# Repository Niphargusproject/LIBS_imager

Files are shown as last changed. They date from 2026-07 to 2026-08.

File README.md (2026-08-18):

# LIBS elemental imager

Design files, firmware and software of a laboratory laser-induced breakdown
spectroscopy (LIBS) elemental imager built from low-cost CNC-derived components,
with a fully hardware-triggered acquisition chain.

The instrument moves the sample under a fixed laser and fixed collection optics on
three ball-screw linear stages driven by the open-source Grbl_ESP32 firmware. The
stepper step pulses of the scan axis are counted and divided by an Arduino-based
pulse controller, which triggers the laser, and the laser in turn triggers the
spectrometers. Shot spacing is therefore locked to stage position instead of to
software timing. A Python/PyQt5 application streams dark-corrected,
wavelength-concatenated spectra into a compressed NetCDF4 hyperspectral cube; a
second application reads those cubes and produces elemental maps, ratios and RGB
composites.

Although it is demonstrated here for LIBS, the motion, triggering and data-cube
chain is technique-agnostic: it can drive other point-by-point mapping methods such
as UV fluorescence, FTIR or Raman imaging.

This repository is the reference implementation for the article:

> C. Burlet, S. Bengattat, X. Devleeschouwer, H. Goethals, T. Goovaerts, M. Rossi,
> G. Stasi, A. Tovar, Y. Vanbrabant, S. Verheyden, R. Barros, S. Nachtergaele,
> E. Pirard. *A Laser-Induced Breakdown Spectroscopy (LIBS) elemental imager built
> from CNC-derived components with a fully hardware-triggered acquisition chain.*
> HardwareX (submitted).

This repository is the living version of the instrument and is where development
continues. The frozen state that produced the results in the article, together with one
measured example data cube, is archived separately on Zenodo,
[10.5281/zenodo.21986499](https://doi.org/10.5281/zenodo.21986499).

## Repository layout

| Path | Content |
| --- | --- |
| `cad/` | STEP models of the laser assembly, the mounting and sample-stage adapter plates, the electronics enclosure and the end-stop board |
| `schematics/` | wiring of the trigger chain and of the internal controller |
| `firmware/` | Arduino sketches of the pulse controller and of the internal controller, and the Grbl_ESP32 settings of the motion controller |
| `software/acquisition_app/` | the acquisition application: device control, mapping engine, NetCDF4 cube writer, GUI |
| `example_data/` | how to get the example cube; the cube itself is too large for GitHub and lives on Zenodo |
| `bill_of_materials.csv` | bill of materials of the article, semicolon-delimited UTF-8 |
| `LICENSES/` | full text of every license used here; see [`LICENSING.md`](LICENSING.md) |

## Quick start

**Motion and triggering.** Flash `firmware/pulse_counter_INT0/` to an Arduino Uno
and `firmware/Libs_leds_distance_sensor_controller/` to an Arduino Nano with the
Arduino IDE, then restore `firmware/Grbl_ESP32_configuration.txt` on the MKS DLC32
board and check it with `$$`. Keep the trigger cable disconnected from the laser
while testing. `firmware/README.md` documents the pin assignment and the serial
command sets.

**Acquisition.** Windows, Python 3.12. The proprietary Avantes `avaspecx64.dll` is not
redistributed here: copy it from your Avantes installation next to `avaspec.py`. Set
the serial ports and the laser IP address in `config.json`, then:

```
cd software/acquisition_app
pip install -r requirements.txt
python app_init.py
```

**Post-processing.** The cubes are read by the LIBS Hypercube Explorer, which has its
own repository. It needs no instrument and no proprietary library, so it also runs on
Linux and macOS:

```
git clone https://github.com/Niphargusproject/LIBS_hypercube_explorer.git
cd LIBS_hypercube_explorer
pip install -r requirements.txt
python Hypercube_explorer.py
```

Output is one NetCDF4 file per map, `{stem}_{timestamp}.nc`, plus progress PNGs and a
pulse-count log. [`software/README.md`](software/README.md) describes the file layout,
and [`example_data/README.md`](example_data/README.md) explains how to fetch a real
cube to try the chain on.

## Safety

The instrument uses a Class 4 pulsed Nd:YAG laser. Build and operate it only with
appropriate engineering controls, an interlocked enclosure, eye protection matched
to 1064 nm and a trained laser operator, following IEC 60825-1 or ANSI Z136.1 and
your institution's laser safety rules. Section 8 of the article describes the
practice used here; it is an illustration, not a substitute for your own risk
assessment.

## Licensing

| Part | License |
| --- | --- |
| Hardware, i.e. everything in `cad/` | CERN-OHL-W-2.0 |
| Firmware and software | GPL-3.0-only |
| Documentation, tables and data | CC-BY-4.0 |
| Third-party icons in `software/acquisition_app/images/` | MIT (Feather, Cole Bemis) |
| Institutional logos and splash screens | not covered, see [`LICENSING.md`](LICENSING.md) |
| `avaspec.py`, `avaspec_fix_winfunctype.py` | Avantes SDK terms, see [`LICENSING.md`](LICENSING.md) |

Per-file licensing is machine-readable in `REUSE.toml`, following the
[REUSE](https://reuse.software) specification. The root `LICENSE` file is the GPL,
which covers the bulk of the repository; `LICENSING.md` explains the exceptions.

## Citing

Cite the article for the design and the Zenodo record for the files. GitHub's
"Cite this repository" button reads `CITATION.cff`.

## Related

* Post-processing application: <https://github.com/Niphargusproject/LIBS_hypercube_explorer>
* Motion firmware: Grbl_ESP32 / FluidNC, <https://github.com/bdring/FluidNC>

## Funding and contact

Developed at the Geological Survey of Belgium (Royal Belgian Institute of Natural
Sciences) within the BELSPO BRAIN-be projects LIBSCREEN and LEAP.

Christian Burlet — cburlet@naturalsciences.be

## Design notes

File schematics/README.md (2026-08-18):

# Schematics

`wiring_trigger_chain.png` is Fig. 7 of the article, at publication resolution, and
`wiring_trigger_chain.pdf` is the same drawing on a 180 × 180 mm page for printing. It
has two panels:

* **(a) the trigger chain.** From the X step output of the MKS DLC32 motion
  controller to the Arduino Uno pulse controller, and from there to the external
  trigger input of the laser, which fans the sync pulse out to the six spectrometers.
  This is the path that locks shot spacing to stage position.
* **(b) the internal controller.** The Arduino Nano inside the laser assembly, its two
  illumination LEDs with their 120 Ω series resistors, and the I²C connection left for
  the time-of-flight distance sensor.

`../firmware/README.md` lists the pins and the serial commands of both boards, and
Section 5 of the article walks through the wiring step by step.

The drawing is a signal-level schematic, not a PCB layout: apart from the end-stop
board in `../cad/`, the electronics are off-the-shelf boards joined by jumper wires
and screw terminals, so there is no board file to publish.

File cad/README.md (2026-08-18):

# CAD

STEP models of the instrument, licensed under CERN-OHL-W-2.0. They open in any CAD
package that reads STEP (FreeCAD, Fusion 360, SolidWorks, Onshape).

| File | Content |
| --- | --- |
| `Screen_libs_v1_imaging_v2026.step.zip` | the laser assembly: focusing head, dichroic mount, collimators, collection arm, camera, and the plate they are mounted on |
| `Screen_libs_pulse_controller_box.step.zip` | enclosure of the electronics, with the motion controller, the pulse controller and the internal controller |
| `Screen_libs_sample_stage_plates.step` | adapter plates between the linear stages and the sample stage |
| `Screen_libs_Z_mounting_plate.step` | plate that carries the Z stage on the vertical optical breadboard |
| `End_Stop_Board_libs.step` | end-stop board of the stages |

Two of the models are zipped because they are 238 MB and 54 MB uncompressed, over
the limit GitHub accepts for a single file. Unzip them before opening; any
archiver, including Windows Explorer, will do.

Fig. 3 of the article is the optical layout of the laser assembly, Fig. 6 shows the
subsystems as built, and Fig. 8 is a render of the first model above with the
enclosure shells removed. Section 5 gives the assembly order and the fasteners. The frame
itself is standard 20 × 40 mm V-slot profile and is not modeled here; its dimensions
are in Section 5 and in the bill of materials.

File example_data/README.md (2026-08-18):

# Example data

The example cube is **not in this repository**: it is 1.35 GB, well over what GitHub
accepts. It is archived on Zenodo with the rest of the design package, under
CC-BY-4.0.

> `Vedrin_01_0.2mm.nc` in [10.5281/zenodo.21986499](https://doi.org/10.5281/zenodo.21986499)

## What it is

An iron ore sample from the Vedrin mine (Belgium), mapped over its full 60 × 40 mm
area at 0.2 mm pitch. It is a complete, unedited output of the acquisition software,
so it doubles as a reference for the file format.

| Property | Value |
| --- | --- |
| Pixels (x × y) | 300 × 200 = 60 000 spectra |
| Mapped area | 60 × 40 mm, shot pitch 0.2 mm |
| Spectral bands | 20 472, from 195.5 to 1031.1 nm, six spectrometers concatenated without gaps |
| Laser | 10 Hz, stage feed 120 mm/min, one shot every 160 step pulses (0.2 mm × 800 steps/mm) |
| Detection | integration time 0.01 ms, delay after trigger 3 µs, 1 accumulation per pixel |
| File size | 1.35 GB compressed, 2.46 GB uncompressed |

`../software/README.md` describes the layout of the file.

## Trying it out

Download the cube from the Zenodo record into this folder, then open it with the
[LIBS Hypercube Explorer](https://github.com/Niphargusproject/LIBS_hypercube_explorer):

```
git clone https://github.com/Niphargusproject/LIBS_hypercube_explorer.git
cd LIBS_hypercube_explorer
python Hypercube_explorer.py
```

Follow the tabs from left to right: load, optionally co-register a photograph, mask
the pixels that are off the sample, normalize, and extract maps. The `help.html` of
that repository explains the options.

In Python, without the application:

```python
import xarray as xr

cube = xr.open_dataset("Vedrin_01_0.2mm.nc")
fe = cube["mapping"].sel(bands=404.581, method="nearest")   # Fe I 404.581 nm
fe.plot(robust=True)
```

The cube is chunked along the spectral axis (256 bands × 1 row × 64 columns), so
reading one wavelength plane takes about 0.2 s. Slice before you compute.

The other maps shown in the article are tens of gigabytes each and are available
from the corresponding author on request.

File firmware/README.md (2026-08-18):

# Firmware

Two Arduino sketches and the settings of the motion controller. Licensed under
GNU GPL v3. Wiring is given in Fig. 7 of the article.

## `pulse_counter_INT0/pulse_counter_INT0.ino` — pulse controller

Runs on an Arduino Uno (ATmega328P). This is the board that makes the acquisition
hardware-triggered.

* The X-axis step line of the motion controller enters on **D2 (INT0)**. Every rising
  edge increments a counter in the interrupt routine.
* When the counter reaches `step_target`, the sketch raises **D4** and the main loop
  drops it 100 µs later, then the counter restarts. The interrupt routine itself never
  waits, so no step pulse can be missed.
* D4 drives the external trigger input of the laser. The shot pitch is therefore
  `step_target / steps_per_mm` millimetres, i.e. `step_target` microsteps of stage
  travel, and does not depend on any software timing.
* Serial interface, 115200 baud, newline-terminated (uses the
  [SerialCommand](http://github.com/p-v-o-s/Arduino-SerialCommand) library):

  | Command | Effect |
  | --- | --- |
  | `STEP <n>` | set the number of microsteps between triggers |
  | `START` | attach the interrupt, i.e. arm the trigger chain |
  | `STOP` | detach the interrupt, i.e. disarm the trigger chain |
  | `COUNT` | number of triggers emitted since the last reset |
  | `RESETCOUNT` | reset that counter |
  | `H` | list the commands |
  | `?` | identify the device (`LIBS motor pulse counter v1.1`) |

  The acquisition application compares `COUNT` with the number of shots it expects
  after every line, which is how a missed or extra trigger is detected.
* `PUMP_ON`, `PUMP_OFF` and `FILTER` are accepted by this version of the sketch but do
  nothing yet; the air pump and the extraction unit are switched by hand. The commands
  are kept so that a relay board can be added on a free output without changing the
  acquisition software.

## `Libs_leds_distance_sensor_controller/Libs_leds_distance_sensor_controller.ino` — internal controller

Runs on an Arduino Nano inside the laser assembly. It switches the two illumination
LEDs and, optionally, reads a distance sensor.

* **D3** drives the micro-view LED and **A3** the macro-view LED, each through a 120 Ω
  series resistor.
* **A2** is the XSHUT (standby) line of a VL53L4CD time-of-flight distance sensor, which
  is read over I²C on SDA/SCL. The sensor is wired but not yet used for automatic focus
  following (article Section 7.8); it starts in standby.
* Serial interface, 115200 baud, newline-terminated: `?`, `H`, `ON` / `OFF` (micro LED),
  `MACRO_LED_ON` / `MACRO_LED_OFF`, `SENSOR_ON` / `SENSOR_OFF`, `DIST` (distance in mm),
  `DIST_DIAG` (distance with status and signal level).
* Needs the `STM32duino VL53L4CD` library (`vl53l4cd_class.h`) from the Arduino library
  manager.

## `Grbl_ESP32_configuration.txt` — motion controller settings

The `$`-settings of the Makerbase MKS DLC32 board running Grbl_ESP32. Restore them by
sending the lines to the controller over the serial console, then check with `$$`.
The header of the file lists the values that matter for imaging (resolution, feed
rates, accelerations) and explains what to change when the mechanics differ.

## Flashing

Both sketches are flashed with the Arduino IDE (board: *Arduino Uno* and
*Arduino Nano*, ATmega328P). No bootloader change or fuse setting is needed. Flash the
boards before they are wired into the machine, and keep the trigger cable
disconnected from the laser while testing.

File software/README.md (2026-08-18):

# Software

`acquisition_app/` is the Fused LIBS acquisition application: it talks to the laser,
the motion controller, the pulse controller, the six spectrometers and the camera,
drives the scan, and writes the hyperspectral cube. Licensed GPL-3.0-only, except the
Avantes wrapper and the logos described in `../LICENSING.md`.

The post-processing application is **not** here. It has its own repository,
[LIBS_hypercube_explorer](https://github.com/Niphargusproject/LIBS_hypercube_explorer):
masking, normalization, elemental maps, ratios, RGB composites, k-means clustering and
co-registration with a photograph of the sample.

## Files

| File | Role |
| --- | --- |
| `app_init.py` | start-up: paths, file checks, logging. This is the entry point |
| `ui_main_window.py`, `mapping_gui.py` | main window and mapping panels (PyQt5) |
| `config.py`, `config.json` | typed configuration and the saved settings of the instrument |
| `device_handlers.py` | discovery and bookkeeping of spectrometers, serial devices and camera |
| `hardware_control.py` | laser (Telnet), motion controller and pulse controller (serial) commands |
| `mapping_engine.py` | the scan loop: arming, line moves, callback collection, NetCDF4 cube writer, progress previews, fault recovery |
| `data_processing.py` | dark correction, wavelength concatenation, band sums |
| `avaspec.py`, `avaspec_fix_winfunctype.py` | ctypes wrapper for the Avantes AvaSpec DLL |
| `test_full_hardware.py` | end-to-end check of laser, motion, pulse controller and spectrometers |
| `test_spectrometer_stress.py` | spectrometer-only soak test, no laser and no motion |
| `help.html` | in-application manual: parameters, file layout, fault recovery |
| `Bruniquel_LIBS_improved.py` | earlier single-file version, kept for reference |
| `launch_LIBS.bat` | Windows launcher: activates the conda base environment and starts the single-file version above |
| `mapping_flowchart.md`, `LIBS_mapping_paper.md` | development notes on the scan loop and the mapping logic |

## Requirements

Windows, because the Avantes and Basler drivers are Windows-only. Python 3.12 and the
packages in `acquisition_app/requirements.txt`. The proprietary `avaspecx64.dll` is
**not** included: copy it from your Avantes installation next to `avaspec.py`.
`pypylon` is only needed for the camera view. Long maps need memory for the growing
cube and its previews, so 16 GB of RAM is comfortable.

## Running

Connect the devices, check the serial ports and the laser IP address in `config.json`,
then:

```
cd acquisition_app
python app_init.py
```

Section 6 of the article gives the operating procedure.

Two habits are worth keeping. Run `test_full_hardware.py` after any rewiring, before
putting a sample in. And watch the pulse count that the application compares with the
expected number of shots at the end of every line: that is what tells you no trigger
was missed.

## Cube layout

Output is one compressed NetCDF4 (HDF5) file per map, `{stem}_{timestamp}.nc`, plus
progress PNGs, one per finished line, and a pulse-count log. The file holds:

* `mapping(bands, y, x)` — `uint16` counts, dark-corrected during acquisition, one
  full spectrum per pixel. Darks are subtracted while scanning and are not stored;
* `bands(bands)` — the wavelength axis in nm, the six spectrometers concatenated in
  ascending order and without gaps;
* global attributes — the acquisition parameters: `step_size_mm`, `steps_per_mm`,
  `step_trigger_steps`, `laser_frequency_hz`, `x_feed_mm_min`, `x_travel_mm`,
  `integration_time_ms`, `integration_delay_ns`, `averages`, `mapping_X_points`,
  `mapping_Y_points`, `mapping_X_size_mm`, `mapping_Y_size_mm`, `bands_total`,
  `devices_total` and `created_utc`;
* one subgroup per spectrometer under `devices` (`device_000` … `device_005`), each
  with its serial number, firmware and DLL versions, first and last wavelength and
  pixel count.

Two attributes show how the shot grid was set. `step_trigger_steps` is the division
factor of the pulse controller, so the shot pitch is
`step_trigger_steps / steps_per_mm` millimetres. And `x_travel_mm` is larger than the
mapped width, 62 mm for a 60 mm map, the extra 2 mm being the over-travel where the
stage accelerates and decelerates outside the sample. Section 2.4 of the article
describes the format in more detail.

Reading a plane with xarray:

```python
import xarray as xr

cube = xr.open_dataset("map_20260217_1032.nc")
fe = cube["mapping"].sel(bands=404.581, method="nearest")   # Fe I 404.581 nm
fe.plot(robust=True)
```

Cubes are chunked along the spectral axis (256 bands × 1 row × 64 columns), which
makes a single wavelength plane cheap to read and the whole cube expensive: a
megapixel map is tens of gigabytes uncompressed. Slice, then compute.

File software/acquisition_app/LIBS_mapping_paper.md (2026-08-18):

# A Synchronized Hardware-Triggered LIBS Mapping System: Implementation and Data Pipeline

**Technical note / Methods paper**

---

## Abstract

We describe the design and implementation of a laser-induced breakdown spectroscopy (LIBS) mapping system in which shot timing is fully determined by a hardware trigger chain: a CNC stage provides step pulses to a pulse controller, which issues trigger signals to both the laser and multiple Avantes spectrometers. The software arms devices, starts motion, and collects spectra via a callback-based acquisition path, writing a continuous hyperspectral cube to NetCDF4/HDF5 with embedded metadata and optional progress previews [6–8]. The architecture avoids software timing jitter, supports multi-device wavelength concatenation and dark correction, and includes automatic laser fault detection and recovery. The platform is designed as **open-source, open-hardware**: motion control is based on GRBL-compatible firmware on a GRBL32-class controller [14–16], the pulse controller is based on an Arduino Uno [13], and mechanical parts are built from low-cost, scalable gantry components with shared 3D models (e.g. via GitHub) consistent with open science hardware practices [17–21,29]. We document the trigger chain, data flow, file format, and key design choices (callback vs. polling, memory-efficient progress imaging, and robust cleanup) so that the approach can be reproduced, scaled, and adapted to other raster-scan measurement techniques.

**Keywords:** LIBS; mapping; hyperspectral; hardware trigger; NetCDF; Avantes; CNC; synchronization.

---

## 1. Introduction

Laser-induced breakdown spectroscopy (LIBS) is widely used for elemental mapping of solid samples [1,2], including imaging and mapping workflows that generate large hyperspectral datasets [3–5]. In typical implementations, the sample is moved under a fixed laser beam (or the beam is scanned), and at each position one or more spectra are acquired. For high spatial resolution over large areas, the number of shots and the volume of spectral data become large; synchronization between laser firing, stage position, and spectrometer integration must be reliable over long runs.

Many systems use software-triggered acquisition: the computer sends a fire command, waits, then reads the spectrometer(s). This introduces latency and jitter and can become a bottleneck at high repetition rates. An alternative is to drive the entire sequence from the motion system: the CNC (or equivalent) produces step pulses that are divided to generate a trigger at every *N* steps, and that trigger is fanned out to the laser and to the spectrometers. The software then only arms the hardware, starts the motion, and collects results as they become available. Shot timing is determined entirely by the stage speed and the step-to-trigger ratio, so it is deterministic and decoupled from software scheduling.

We implemented such a system using a GRBL-controlled CNC stage, a custom pulse controller, a Viron laser, and multiple Avantes spectrometers. The control and acquisition software is written in Python [11] and integrates with a PyQt5-based laboratory application [12]. Data are written in near real time to a NetCDF4 file, forming a hyperspectral cube (bands × *y* × *x*) with metadata and device information [6–8]. In addition to describing the mapping process, we highlight the system’s open-hardware philosophy—shared designs, commodity components, and modifiable controller firmware—aligned with the open science hardware community [17–20]. This document describes the trigger chain, callback-based acquisition, file format, and fault-recovery strategy, with the aim of providing a reference for reproducible, scalable LIBS mapping and for adaptation to other raster-scan measurement modalities.

---

## 2. Materials and Methods

### 2.1 Hardware chain and trigger synchronization

The mapping system comprises four hardware subsystems used in a single coordinated workflow:

1. **CNC stage and motion controller (GRBL32-class, open source / open hardware)**  
   A three-axis gantry stage driven by stepper motors. The X-axis is used for the main scan direction along each line; the Y-axis advances between lines. Motion is commanded over a serial link using GRBL-compatible jog commands. In our implementation the controller is a **GRBL32-class board** (32-bit GRBL ecosystem) running open-source firmware (e.g. GRBL [14] or 32-bit derivatives such as grblHAL or FluidNC) [15,16]. The controller emits step pulses (e.g. 800 steps/mm) that are available as a digital output. The gantry is built from commodity, easily sourced components (e.g. extrusion/rails/motors) and is readily scalable by changing rail lengths and workspace dimensions, consistent with open labware and open hardware practices [19–22].

2. **Pulse controller (Arduino Uno)**  
   A custom unit based on an Arduino Uno microcontroller [13] that receives step pulses from the CNC and, after a programmable number of steps (*step_trigger*), outputs a single trigger pulse. That pulse is fanned out to the laser (external trigger input) and to the spectrometer(s) (external trigger input for integration start). Thus, one trigger is issued every *step_trigger* motor steps, i.e. every spatial step of size *step_size* = *step_trigger* / *steps_per_mm* (mm). Using a widely available open microcontroller platform simplifies replication and modification of the trigger logic [13,19].

3. **Laser (Viron)**  
   The laser is controlled via a TCP (telnet-like) interface. For mapping it is placed in external-trigger mode: it fires on each trigger pulse and remains in a “fire” state for the whole mapping run. No software command is sent between scan lines; only the first line involves a warm-up sequence (standby → ready → fire). This minimizes command traffic and avoids CAN-bus overrun issues observed when sending frequent commands.

4. **Spectrometers (Avantes)**  
   One or more Avantes spectrometers are used, each with its own wavelength range. They are configured for external trigger and a fixed number of scans per line (*x_points*). The SDK provides a callback API: when a scan completes, a DLL callback runs and the application can move the result into a thread-safe queue. The mapping thread blocks on the queue instead of polling, which reduces CPU load and avoids accumulated polling overhead over long runs.

The trigger chain is therefore:

```
CNC step pulses  →  Pulse controller (divide by step_trigger)  →  Trigger out
                                                                       ├→ Laser (fire)
                                                                       └→ Spectrometers (start integration)
```

The software does not control shot timing; it only sets *step_trigger*, starts the CNC motion, and collects spectra as they are delivered by the callback mechanism.

### 2.1.1 Open-source/open-hardware implementation and scalability

The mapping platform is distributed as **open source** (software) and **open hardware** (mechanical and electronic designs) in the sense of the OSHWA definition: design files are made publicly available so others can study, modify, make, and redistribute them [17]. Community frameworks such as GOSH emphasize accessibility, local manufacturability, repairability, and reproducibility as core goals for scientific instrumentation [18].

In practice, the system’s scalability and modifiability come from three design choices:

- **Motion control in the GRBL ecosystem:** GRBL provides a well-documented, widely adopted motion control stack; 32-bit GRBL-compatible controllers (GRBL32-class) extend capabilities while preserving the G-code/jog model [14–16].
- **Commodity, modular gantry mechanics:** The stage is built from low-cost, easily replaceable components; scaling the mapping area is primarily a mechanical redesign (rail/extrusion length and cable management), not a software rewrite. This approach mirrors established open hardware strategies in scientific tooling [19–22].
- **Programmable trigger logic:** Implementing the pulse controller on Arduino Uno reduces barriers to modifying trigger division, gating, or adding auxiliary outputs (e.g. camera strobe, shutter, or safety interlocks) [13,19].

Design files (including 3D models) can be hosted on collaborative platforms such as GitHub for versioned distribution and citation support (e.g. `CITATION.cff`) [28,29]. Hardware designs can be licensed using established open hardware licenses (e.g. CERN OHL v2 or TAPR OHL), enabling reuse and reciprocity while clarifying redistribution terms [23,24].

### 2.2 Mapping parameters and derived quantities

User-defined parameters include:

- **Spatial:** *step_size* (mm), *mapping_X_size*, *mapping_Y_size* (mm).
- **Laser:** *laser_frequency* (Hz), *line_start_wait_s* (s) — wait after first fire before starting the first line.
- **Spectrometer:** *integration_time_ms*, *integration_delay_ns*, *averages* (typically 1 for mapping).
- **CNC:** *steps_per_mm*, *return_feed_mm_min* (mm/min for the return jog).

Derived quantities used in the implementation are:

- *mapping_X_points* = *mapping_X_size* / *step_size*  
  (number of shots per line)
- *mapping_Y_points* = *mapping_Y_size* / *step_size*  
  (number of lines)
- *x_speed_mm_s* = *step_size* × *laser_frequency*  
  (scan speed in mm/s so that one shot occurs per step)
- *x_feed_mm_min* = *x_speed_mm_s* × 60  
  (GRBL feed in mm/min)
- *step_trigger* = round(*steps_per_mm* × *step_size*)  
  (steps per trigger pulse)
- *x_travel_mm* = *mapping_X_size* + 10 × *step_size*  
  (forward travel including a margin so that extra triggers are available after the last pixel; these “margin” shots compensate for occasional laser misfires)

The CNC jog distance is *x_travel_mm* + 1 mm (additional safety margin). After the line, the stage returns to the start at *return_feed_mm_min*.

### 2.3 Software workflow

The mapping run is executed in a dedicated background thread. Pre-established connections (serial for CNC and pulse controller, TCP for laser, USB for spectrometers) are passed in; the mapping code does not open or close them.

**One-time setup:**

1. Laser: login, configure for mapping (external trigger, burst off, appropriate quiescent/prefire settings), then for the first line only: standby → wait ready → fire → wait *line_start_wait_s*.
2. Create the NetCDF file (see 2.5).
3. Capture a dark spectrum per device (software trigger, one scan per spectrometer).
4. Build pixel ranges and wavelength concatenation for all devices; initialise the callback-based collector.

**Per-line loop (for each *y* = 0 … *mapping_Y_points* − 1):**

1. If *y* = 0 and first attempt: run full laser standby-and-fire sequence; otherwise no laser commands (laser stays in fire).
2. Arm spectrometers: `AVS_PrepareMeasure` (external trigger, *x_points* scans) and `AVS_MeasureCallback` (callback + queue per handle). Drain any leftover items from the queues from the previous line.
3. Arm pulse controller: send step divisor (*step_trigger*) and start.
4. Start CNC: jog X by the computed distance at *x_feed_mm_min*.
5. For each *x* = 0 … *mapping_X_points* − 1: block on the collector’s queues until one scan is available from every device; dark-correct and merge into a single band vector; write that vector to the NetCDF at (*x*, *y*); release the per-*x* buffer.
6. After the last *x*: call `AVS_StopMeasure` on all devices (critical for resetting DLL/USB state and avoiding desynchronisation over many lines).
7. Wait for CNC idle (forward jog, including margin, complete). Then stop the pulse controller, jog X back to line start at return feed, wait for idle, flush NetCDF.
8. If at any *x* no data arrive within *shot_timeout_s* (e.g. 30 s), treat as laser fault: stop triggers, stop measure, wait CNC, return stage, raise timeout. The main loop then runs a recovery sequence (see 2.4) and retries the same line up to *max_line_retries* times.
9. After a successful line: update progress; move Y by *step_size*; every *progress_every_lines* lines, generate a progress PNG (see 2.6) and optionally upload via FTP.

**Cleanup (always, in a `finally` block):**  
Laser: send stop. Close the NetCDF file. The GUI then disconnects the laser and resumes camera/illumination if they were paused for mapping.

### 2.4 Laser fault detection and recovery

If the laser stops firing (e.g. fault or interlock), the spectrometers stop receiving triggers and the callback-based collector does not receive new data. After *shot_timeout_s* seconds at one *x*, a `ShotTimeoutError` is raised. The mapping thread:

1. Stops the pulse controller and calls `AVS_StopMeasure` on all spectrometers.
2. Waits for the CNC to finish the current jog and returns the stage to the line start.
3. Runs a recovery sequence: login → `$STOP` → wait 30 s → reconfigure for mapping → `$STANDBY` → wait 5 s → poll status until “ready” (up to 120 s) → `$FIRE` → wait *line_start_wait_s*.
4. Retries the same line. If timeouts persist after *max_line_retries* attempts, the mapping aborts with an error.

All laser commands are separated by a minimum gap (e.g. 1 s) to avoid CAN-bus overrun. A 0.5 s delay is applied after login.

### 2.5 Data format (NetCDF4)

The output file is NetCDF4 with:

- **Dimensions:** `bands`, `y`, `x`.  
  `bands` is the total number of spectral channels (sum of pixel counts over all devices after concatenation). `y` and `x` are *mapping_Y_points* and *mapping_X_points*.

- **Variables:**  
  - `mapping` (`uint16`, dimensions `bands` × `y` × `x`): hyperspectral cube. Stored with zlib compression (level 4), chunked (e.g. 256 bands × 1 × 64) and shuffle for efficient partial I/O.  
  - `bands` (`float64`, dimension `bands`): wavelength (nm) for each channel in concatenated order.

- **Global attributes:** Creation time (UTC), integration time, delay, averages, laser frequency, step size, steps per mm, step trigger, travel and feed settings, grid dimensions, band count, device count, progress selection and tolerance.

- **Group `devices`:** One subgroup per device (`device_000`, …) with attributes: handle, serial, user_friendly_name, FPGA/firmware/DLL versions, wavelength range, pixel count.

Each pixel (*x*, *y*) is written as a single vector: dark-corrected intensities from all devices, merged in device order, clipped to [0, 65535] and stored as `u2`. Writes are incremental; `sync()` is called after each line. NetCDF4 builds on HDF5 to provide a self-describing container with compression and chunked I/O [6–8].

### 2.6 Progress preview and memory use

Every *progress_every_lines* lines, a preview image is generated from the current NetCDF file: a user-selected element (e.g. Sr) defines wavelength bands (with a tolerance in nm); the corresponding bands are summed over the cube. To avoid loading the full cube into memory, bands are summed one at a time (read one band slab, add to an accumulator, discard slab). The result is saved as a PNG with Matplotlib [9]; the figure is explicitly closed in a `finally` block to prevent figure leaks. The same PNG can be uploaded to an FTP server for remote monitoring.

### 2.7 Callback-based acquisition

The Avantes SDK allows either polling (`AVS_PollScan`) or callback (`AVS_MeasureCallback`). We use the callback: for each device, a small callback stores a result token in a per-handle queue; the mapping thread calls `queue.get(timeout=shot_timeout_s)` for each device in turn. This avoids busy-waiting and reduces CPU use and sensitivity to thread scheduling over long runs. The callback function reference is kept on the collector object to prevent garbage collection of the ctypes trampoline. After each line, `AVS_StopMeasure` is called on every device so that internal buffers are cleared and devices stay synchronized over hundreds of lines.

### 2.8 Extending the platform beyond LIBS

Because the system is a general raster-scan positioning platform with a deterministic hardware trigger chain, it can be adapted to other spatially resolved measurements by replacing the probe head and reusing the motion + synchronization infrastructure. Examples include:

- **Raman mapping** (substituting a Raman probe and spectrometer; scanning strategies and throughput constraints are well described in Raman imaging reviews) [25].
- **X-ray fluorescence (XRF) mapping** (mounting an XRF source/detector head on the gantry or using a fixed head with stage motion) [26].
- **Laser ablation ICP-MS (LA-ICP-MS) imaging** (using a raster ablation source with stage motion and synchronizing acquisition to line scans) [27].

More broadly, the same architecture can support reflectance/hyperspectral imaging, laser-induced fluorescence, photoluminescence mapping, or automated microscopy, provided the measurement subsystem offers either hardware trigger inputs or robust timestamping; open hardware microscopy projects provide precedents for scalable, locally manufacturable mechatronics and control software [22].

---

## 3. Results and design validation

### 3.1 Timing and throughput

For a nominal configuration (e.g. *step_size* = 0.1 mm, *laser_frequency* = 20 Hz, *mapping_X_size* = 20 mm, *mapping_Y_size* = 3 mm, *steps_per_mm* = 800, *return_feed_mm_min* = 100):

- *mapping_X_points* = 200, *mapping_Y_points* = 30.
- Scan speed = 0.1 × 20 = 2 mm/s; *x_feed_mm_min* = 120 mm/min.
- *step_trigger* = 80 steps; one shot every 50 ms.
- Forward travel ≈ 22 mm → forward time ≈ 11 s; return ≈ 13 s; total per line ≈ 24 s (plus arm and flush). Scan efficiency (forward scan time vs. total line time) is on the order of 40%; the rest is return and overhead.

The software provides duration and file-size estimates before the run using the same formulas as in Section 2.2 and a simple compression model (e.g. 0.6× raw size for the main array).

### 3.2 Stability over long runs

Without calling `AVS_StopMeasure` after each line, the spectrometers’ internal state can diverge after on the order of 200 lines (observed as timeouts or missing data). With `AVS_StopMeasure` in a `finally` block after every line (success or failure), runs of hundreds of lines complete without desynchronisation. The callback-based path and the disciplined laser command pacing (no commands between lines, 1 s gap between commands, 30 s cool-down after stop before standby) have been used to run full multi-hour maps without CAN-bus or communication errors.

### 3.3 Resource and integration notes

- **Memory:** Per-line buffers are released after each pixel; progress PNG generation uses incremental band summation and explicit figure close; no unbounded in-memory growth is expected over long runs.
- **Camera:** The GUI pauses the laboratory camera during mapping and resumes it in the finalization step (on both normal completion and error), so the camera lifecycle is consistent.
- **Identities:** When a subset of spectrometers is selected, device metadata (identities) is filtered to match the selected handles so that NetCDF device groups correspond to the devices actually used.

---

## 4. Discussion

The main design choices were:

1. **Hardware-driven timing** so that shot rate and spatial step are set by the stage and pulse controller, not by software loops.
2. **Callback-based spectrometer readout** to avoid polling overhead and improve reliability over long acquisitions.
3. **Single fire state for the laser** for the whole map, with a full recovery sequence only on timeout, to minimise command traffic and CAN-bus load.
4. **Systematic `AVS_StopMeasure`** after every line to keep spectrometer state and buffers consistent across many lines.
5. **NetCDF4** for a self-describing, chunked, compressed cube with metadata and device info, suitable for downstream analysis in Python, MATLAB, or other tools.
6. **Progress preview** with bounded memory (incremental band sum) and explicit cleanup of Matplotlib figures.

In addition, the system is intentionally aligned with open hardware/open science hardware principles—commodity components, shareable CAD, and modifiable firmware—so the mapping area can be scaled and the platform can be repurposed to other raster-scan modalities without redesigning the full stack [17–22,25–27].

Limitations include: the return phase is slower than the forward scan, so scan efficiency is below 50%; the current implementation does not support on-the-fly change of step size or laser frequency mid-run; and app exit during mapping may block until the user stops the run or the thread finishes, unless the application explicitly sets a stop event and waits for the thread with a timeout on close.

---

## 5. Conclusion

We have described a synchronized, hardware-triggered LIBS mapping implementation in which the CNC stage drives the trigger chain and the software arms devices, starts motion, and collects spectra via callbacks into a streaming NetCDF4 cube. The design avoids software timing jitter, supports multi-device concatenation and dark correction, and includes fault detection and recovery. The document provides enough detail on parameters, trigger chain, data format, and software workflow to reproduce or adapt the approach for other LIBS mapping systems.

---

## References

1. Cremers, D. A., & Radziemski, L. J. (2006). *Handbook of Laser-Induced Breakdown Spectroscopy*. Wiley.
2. Noll, R. (2012). *Laser-Induced Breakdown Spectroscopy*. Springer.
3. Limbeck, A., Brunnbauer, L., Lohninger, H., Pořízka, P., Modlitbová, P., Kaiser, J., Janovszky, P., Kéri, A., & Galbács, G. (2021). Methodology and applications of elemental mapping by laser induced breakdown spectroscopy. *Analytica Chimica Acta*, 1147, 72–98. https://doi.org/10.1016/j.aca.2020.12.054
4. Senesi, G. S. (2014). Laser-Induced Breakdown Spectroscopy (LIBS) applied to terrestrial and extraterrestrial analogue geomaterials with emphasis to minerals and rocks. *Earth-Science Reviews*. https://doi.org/10.1016/j.earscirev.2014.09.008
5. Galbács, G. (2015). A critical review of recent progress in analytical laser-induced breakdown spectroscopy. *Analytical and Bioanalytical Chemistry*, 407, 7537–7562. https://doi.org/10.1007/s00216-015-8855-3
6. Rew, R. K., & Davis, G. P. (1990). NetCDF: An interface for scientific data access. *IEEE Computer Graphics and Applications*, 10(4), 76–82. https://doi.org/10.1109/38.56302
7. Eaton, B., Gregory, J., Drach, B., Taylor, K., Hankin, S., et al. (2025). *NetCDF Climate and Forecast (CF) Metadata Conventions* (Version 1.13). CF Community. https://doi.org/10.5281/zenodo.17801666
8. The HDF Group. (2024). *HDF5 File Format Specification* (v3.0). https://support.hdfgroup.org/HDF5/doc/H5.format.html
9. Hunter, J. D. (2007). Matplotlib: A 2D graphics environment. *Computing in Science & Engineering*, 9(3), 90–95. https://doi.org/10.1109/MCSE.2007.55
10. Harris, C. R., Millman, K. J., van der Walt, S. J., et al. (2020). Array programming with NumPy. *Nature*, 585, 357–362. https://doi.org/10.1038/s41586-020-2649-2
11. Van Rossum, G., & Drake, F. L. (2009). *Python 3 Reference Manual*. CreateSpace.
12. Riverbank Computing. (2024). *PyQt5 Documentation*. https://www.riverbankcomputing.com/static/Docs/PyQt5/
13. Arduino. (n.d.). *Arduino Uno Rev3*. https://docs.arduino.cc/hardware/uno-rev3
14. Jeon, S. (Sonny) and contributors. (2019). *GRBL (gnea/grbl)* (v1.1h). GitHub repository. https://github.com/gnea/grbl
15. grblHAL/core contributors. (n.d.). *grblHAL core*. GitHub repository. https://github.com/grblHAL/core
16. Dring, B. and contributors. (n.d.). *FluidNC*. GitHub repository and documentation. https://github.com/bdring/FluidNC ; http://wiki.fluidnc.com/home
17. Open Source Hardware Association (OSHWA). (n.d.). *Open Source Hardware Definition 1.0*. https://oshwa.org/resources/open-source-hardware-definition/
18. Dosemagen, S., Liboiron, M., & Molloy, J. (2017). Gathering for Open Science Hardware 2016. *Journal of Open Hardware*, 1(1), 5. https://doi.org/10.5334/joh.5
19. Pearce, J. M. (2012). Building research equipment with free, open-source hardware. *Science*, 337(6100), 1303–1304. https://doi.org/10.1126/science.1228183
20. Baden, T., Chagas, A. M., Gage, G., Marzullo, T., Prieto-Godino, L. L., & Euler, T. (2015). Open Labware: 3-D printing your own lab equipment. *PLOS Biology*, 13(3), e1002086. https://doi.org/10.1371/journal.pbio.1002086
21. Jones, R., Haufe, P., Sells, E., Iravani, P., Olliver, V., Palmer, C., & Bowyer, A. (2011). RepRap – the replicating rapid prototyper. *Robotica*, 29(1), 177–191. https://doi.org/10.1017/S026357471000069X
22. Collins, J. T., Knapper, J., Stirling, J., et al. (2020). Robotic microscopy for everyone: the OpenFlexure microscope. *Biomedical Optics Express*, 11(5), 2447–2460. https://doi.org/10.1364/BOE.385729
23. CERN. (2020). *CERN Open Hardware Licence v2* (OHL-P/W/S). License texts: https://ohwr.org/cern_ohl_p_v2.txt ; https://ohwr.org/cern_ohl_w_v2.txt ; https://ohwr.org/cern_ohl_s_v2.txt
24. TAPR. (2007). *TAPR Open Hardware License v1.0*. https://files.tapr.org/OHL/TAPR_Open_Hardware_License_v1.0.txt
25. Opilik, L., Schmid, T., & Zenobi, R. (2013). Modern Raman imaging: Vibrational spectroscopy on the micrometer and nanometer scales. *Annual Review of Analytical Chemistry*, 6, 379–398. https://doi.org/10.1146/annurev-anchem-062012-092646
26. Vanhoof, C., Bacon, J. R., Fittschen, U. E. A., & Vincze, L. (2022). Atomic spectrometry update: review of advances in X-ray fluorescence spectrometry and its special applications. *Journal of Analytical Atomic Spectrometry*, 37, 1761–1775. https://doi.org/10.1039/D2JA90035A
27. Becker, J. S., Matusch, A., & Wu, B. (2014). Bioimaging mass spectrometry of trace elements – recent advance and applications of LA-ICP-MS: A review. *Analytica Chimica Acta*, 835, 1–18. https://doi.org/10.1016/j.aca.2014.04.048
28. Chacon, S., & Straub, B. (2014). *Pro Git* (2nd ed.). Apress.
29. GitHub Docs. (n.d.). About citation files (`CITATION.cff`). https://docs.github.com/en/repositories/managing-your-repositorys-settings-and-features/customizing-your-repository/about-citation-files

---

## Data and code availability

The mapping engine, GUI components, and flowchart documentation are part of the Fused LIBS application. NetCDF4 files produced by the system contain full acquisition parameters and device metadata for reproducibility.

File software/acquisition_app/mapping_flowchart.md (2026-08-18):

# Mapping Run Flow Chart

## Overview

This diagram traces the complete mapping acquisition flow from the GUI button click
through hardware control, data acquisition, and NetCDF file writing.

### Color legend

| Color | Meaning |
|---|---|
| 🔵 Blue | GUI actions (PyQt main thread) |
| 🟣 Purple | Background thread (MappingThread — all mapping runs here) |
| 🟢 Green | Successful operations / data writes |
| 🔶 Amber | Decision points |
| 🔴 Red | Errors / fault path |
| 🟠 Orange | Laser fault recovery sequence |
| ⚫ Grey | Final cleanup (always runs) |

## Flow Chart

```mermaid
flowchart TB
    classDef gui fill:#2563eb,stroke:#1e40af,color:#fff
    classDef thread fill:#7c3aed,stroke:#5b21b6,color:#fff
    classDef success fill:#16a34a,stroke:#14532d,color:#fff
    classDef decision fill:#d97706,stroke:#92400e,color:#fff
    classDef error fill:#dc2626,stroke:#7f1d1d,color:#fff
    classDef recovery fill:#ea580c,stroke:#7c2d12,color:#fff
    classDef cleanup fill:#64748b,stroke:#334155,color:#fff

    subgraph MAIN_THREAD ["MAIN THREAD  —  PyQt GUI  (Bruniquel_LIBS_improved.py)"]
        direction LR
        A["🖱 User clicks\nStart Mapping"]:::gui
        A --> B["_build_mapping_params()\nread BasicParamsTab\n+ AdvancedParamsTab"]:::gui
        B --> VAL{"All devices\nconnected?\nCNC · Pulse\nLaser · Spectro"}:::decision
        VAL -->|No| ERR1["❌ Abort\nshow error"]:::error
        VAL -->|Yes| PRE["_ensure_mapping_laser_ready()\nPause camera & light"]:::gui
        PRE --> SPAWN["Create MappingThread\nwith pre-established\nserial/network handles"]:::gui
        SPAWN --> START["thread.start()"]:::gui
    end

    START ==>|"spawns\nbackground\nthread"| RUN

    subgraph SETUP ["BACKGROUND THREAD ①  —  One-time setup  (MappingEngine.run)"]
        direction LR
        RUN["MappingEngine.run()"]:::thread
        RUN --> LOGIN["Laser: ensure_session()\n$LOGIN + 0.5 s settle"]:::thread
        LOGIN --> LCFG["Laser: configure_for_mapping()\n$TRIG EI · $BURST 0\n$QSPRE 1 · $QSON 1\n(1 s gap between each)"]:::thread
        LCFG --> NC["Create NetCDF file\n+ build device metadata\n+ concatenate wavelengths"]:::thread
        NC --> DARK["Capture dark spectrum\n(software trigger, 1 scan\nper spectrometer, polling)"]:::thread
        DARK --> COLL["Create CallbackCollector\n(reused across all lines)"]:::thread
    end

    COLL ==> YLOOP

    subgraph YLINE_LOOP ["BACKGROUND THREAD ②  —  Y-line scan loop  (for y = 0 .. Y-1, with fault recovery)"]
        direction LR
        YLOOP["▶ Next Y line"]:::thread
        YLOOP --> STOPCHK{"stop_event\nset?"}:::decision
        STOPCHK -->|"Yes (user\npressed Stop)"| DONE["→ go to\ncleanup"]:::cleanup

        STOPCHK -->|No| RESYNCCHK{"y % resync_every_n_lines == 0?\n(default: every 50 lines,\nexcept y=0)"}:::decision
        RESYNCCHK -->|Yes| SRESYNC["Spectrometer full re-init\n(Stop/Deactivate/Done/Discover)\nRemap dark (no new dark)\nRebuild callback collector"]:::thread
        RESYNCCHK -->|No| RETRY["Attempt 1 ..\nmax_line_retries\n(default 3)"]:::thread
        SRESYNC --> RETRY
        RETRY --> FIRSTCHK{"First line\n(y=0)?"}:::decision
        FIRSTCHK -->|Yes| LFIRE["standby_and_fire()\n$LOGIN · $STANDBY\nwait_ready (90 s)\n$FIRE + 5 s wait"]:::thread
        FIRSTCHK -->|No| NOLASER["No laser commands\n(stays in $FIRE)"]:::thread
        LFIRE --> XSCAN["_scan_single_line(y)\nsee detail below ⬇"]:::thread
        NOLASER --> XSCAN

        XSCAN -->|"✅ Line OK"| PROG["Update\nprogress %"]:::success
        XSCAN -->|"⚠ ShotTimeoutError\n(timeout / pulse count check\nfailure)"| RCHK{"Retries\nexhausted?"}:::decision

        RCHK -->|Yes| FATAL["❌ RuntimeError\npersistent laser fault\nabort mapping"]:::error
        FATAL --> DONE
        RCHK -->|No| REC["_recover_laser()\n+ spectrometer re-init\nsee detail below ⬇"]:::recovery
        REC --> RETRY

        PROG --> YLAST{"Last Y\nline?"}:::decision
        YLAST -->|No| JOGY["CNC: jog_y\n+step_size mm\nwait idle"]:::thread
        YLAST -->|Yes| PNGCHK
        JOGY --> PNGCHK{"Every N\nlines?"}:::decision
        PNGCHK -->|Yes| PNG["Save progress PNG\n(incremental band sum)\n+ optional FTP"]:::success
        PNGCHK -->|No| YLOOP
        PNG --> YLOOP
    end

    DONE ==> CLEANUP_START

    subgraph CLEANUP_BLOCK ["BACKGROUND THREAD ③  —  Cleanup  (always runs in finally block)"]
        direction LR
        CLEANUP_START["Laser: $LOGIN\nthen $STOP"]:::cleanup
        CLEANUP_START --> NCCLOSE["Close NetCDF file"]:::cleanup
        NCCLOSE --> SIGNAL["Log completion\nSignal 100 % to GUI\nRestore camera & light"]:::cleanup
    end
```

## ⬇ Detail: `_scan_single_line(y)` — one X-line acquisition

```mermaid
flowchart LR
    classDef thread fill:#7c3aed,stroke:#5b21b6,color:#fff
    classDef success fill:#16a34a,stroke:#14532d,color:#fff
    classDef decision fill:#d97706,stroke:#92400e,color:#fff
    classDef error fill:#dc2626,stroke:#7f1d1d,color:#fff

    subgraph ARM ["Phase 1 — Arm hardware"]
        direction TB
        A1["CallbackCollector.arm()\nAVS_PrepareMeasure()\neach spectrometer:\next. trigger mode\nx_points scans\nAVS_MeasureCallback()"]:::thread
        A1 --> A2["Pulse controller:\nRESETCOUNT · STEP n · START\n(armed, listening to\nCNC step signals)"]:::thread
        A2 --> A3["CNC: grbl_stream_jog_x()\nforward x_travel + margin\n→ CNC starts moving,\ntrigger chain is live"]:::thread
    end

    ARM --> COLLECT

    subgraph COLLECT ["Phase 2 — Collect spectra  (CNC moving, triggers firing autonomously)"]
        direction TB
        C1["for x = 0 .. mapping_X_points - 1"]:::thread
        C1 --> C2["CallbackCollector.collect_next_shot()\nblocks on Queue.get(timeout)\nDLL callback fires when\ndata ready — no polling"]:::thread
        C2 -->|"Data ready\n(all spectrometers)"| C3["Dark-correct\nMerge across devices\nncw.write_xy(x, y)"]:::success
        C3 --> C1
    end

    C1 -->|"All x_points\ncollected ✅"| SUCCESS_PATH
    C2 -->|"Timeout ⚠\n(or pulse count < expected)"| FAULT_PATH

    subgraph SUCCESS_PATH ["Phase 3a — Success cleanup"]
        direction TB
        S0["AVS_StopMeasure()\non all spectrometers\n(reset DLL/USB state)"]:::success
        S0 --> S1["movement_trigger_stop()\nimmediately after\nlast acquired point"]:::success
        S1 --> S2["wait_cnc_idle()\nCNC finishes full jog"]:::success
        S2 --> S3["Read pulse COUNT\n(log to CSV)\naccept if COUNT >= expected"]:::success
        S3 --> S4["CNC: return to X start\n(fast return feed)"]:::success
        S4 --> S5["Flush NetCDF to disk"]:::success
    end

    subgraph FAULT_PATH ["Phase 3b — Fault cleanup"]
        direction TB
        F1["movement_trigger_stop()\nSTOP immediately\n(laser is faulted)"]:::error
        F1 --> F2["AVS_StopMeasure()\non all spectrometers\n(reset DLL/USB state)"]:::error
        F2 --> F3["wait_cnc_idle()\n(CNC finishes its jog)"]:::error
        F3 --> F4["Read pulse COUNT\n(log to CSV)"]:::error
        F4 --> F5["CNC: return to X start"]:::error
        F5 --> F6["Raise ShotTimeoutError\n→ main loop retries"]:::error
    end
```

## ⬇ Detail: recovery between retries (`_recover_laser` + spectrometer re-init)

```mermaid
flowchart LR
    classDef recovery fill:#ea580c,stroke:#7c2d12,color:#fff
    classDef decision fill:#d97706,stroke:#92400e,color:#fff

    R1["$LOGIN\n(ensure_session)\n+ 0.5 s"]:::recovery
    R1 --> R2["$STOP\ntake laser out\nof FIRE mode"]:::recovery
    R2 --> R3["Wait 30 s\nfor laser\nto settle"]:::recovery
    R3 --> R4["configure_for_mapping()\n$LOGIN + 0.5 s\n$TRIG EI · $BURST 0\n$QSPRE 1 · $QSON 1\n(1 s gap each)"]:::recovery
    R4 --> R5["$STANDBY\n+ 5 s settle"]:::recovery
    R5 --> R6["wait_ready()\npoll every 2 s\nup to 120 s"]:::recovery
    R6 --> R7{"Laser\nready?"}:::decision
    R7 -->|Yes| R8["$FIRE + 5 s\nSpectrometer re-init:\nStop/Deactivate/Done/Discover\nremap dark + rebuild collector\n✅ Retry same Y line"]:::recovery
    R7 -->|"No (wait_ready\ntimeout)"| R9["❌ RuntimeError\npropagates up\nmapping aborts"]:::recovery
```

## Laser telnet command timeline

All commands enforced with **1 s minimum gap** (`CMD_GAP_S`) and **0.5 s** settle after `$LOGIN`.

### Normal mapping (no faults)

```
INIT:     $LOGIN → $TRIG EI → $BURST 0 → $QSPRE 1 → $QSON 1 → $STATUS? ×2
LINE 0:   $LOGIN → $STANDBY → [wait_ready: $STATUS? ×2 per poll] → $FIRE → 5s
LINE 1:   (nothing)
LINE 2:   (nothing)
...
LINE N:   (nothing)
END:      $LOGIN → $STOP
```

### With a fault recovery at line K

```
...
LINE K:   (timeout / pulse parity failure detected)
RECOVER:  $LOGIN → $STOP → 30s → $LOGIN → $TRIG EI → $BURST 0 → $QSPRE 1
          → $QSON 1 → $STANDBY → 5s → [wait_ready: $STATUS? ×2, poll 2s, max 120s]
          → $FIRE → 5s → spectrometer re-init
LINE K:   (retry — no laser commands)
...
```

## Hardware trigger chain (during CNC movement)

```
CNC stepper motor  ──step pulses──→  Pulse controller  ──(every N steps)──→  Trigger pulse out
                                                                                   │
                                                              ┌────────────────────┤
                                                              ▼                    ▼
                                                         Laser fires         Spectrometers
                                                         (ext. trigger)      start integration
                                                              │                    │
                                                              ▼                    ▼
                                                         Plasma emission  →  Spectrum captured
```

The software does **not** control shot timing. The hardware trigger chain runs autonomously
at the CNC's movement speed. The software arms everything, starts the motion, and collects
results as fast as they arrive.

## Timing diagram — single scan line

### Computed example values

| Parameter | Value | Formula / Source |
|---|---|---|
| step_size | 0.1 mm | user setting |
| laser_frequency | 20 Hz | user setting |
| mapping_X_size | 20 mm | user setting |
| CNC acceleration | 500 mm/s² | GRBL $120 |
| steps_per_mm | 800 | GRBL $100 |
| return_feed | 100 mm/min | MappingParams default |
| | | |
| mapping_X_points | **200** | 20 / 0.1 |
| scan speed | **2 mm/s** (120 mm/min) | 0.1 × 20 |
| step_trigger | **80 steps** | 800 × 0.1 |
| shot interval | **50 ms** | 1 / 20 |
| x_travel | **21 mm** | 20 + (0.1 × 10) |
| jog distance | **22 mm** | x_travel + 1 (code margin) |
| CNC accel time | **4 ms** | 2 / 500 |
| CNC accel distance | **0.004 mm** | 2² / (2 × 500) |
| time to first trigger | **~52 ms** after CNC start | 4 ms accel + 48 ms at 2 mm/s |
| forward scan time | **11.0 s** | 22 / 2 |
| return time | **13.2 s** | 22 / (100/60) |
| **total line time** | **~24.4 s** | arm + scan + return |
| scan efficiency | **~41 %** | 10.1 / 24.4 (return dominates) |

### Full line overview (~24 s)

```mermaid
gantt
    title Single scan line — 20 Hz · 0.1 mm · 200 pts · 22 mm jog
    dateFormat x
    axisFormat %M:%S
    tickInterval 2000

    section Software
    Arm spectro (callback) + pulse (120 ms)  :done, 0, 120
    Send JOG command                         :done, 120, 170
    Collect (callback queue) ×200 pts        :active, 170, 10070
    AVS_StopMeasure (all devices)            :crit, 10070, 10100
    STOP triggers (immediate)                :crit, 10070, 10120
    Wait CNC idle                            :10120, 11120
    Read COUNT (>= expected)                 :done, 11120, 11170
    Send return JOG                          :done, 11170, 11220
    Wait CNC return (13.2 s @ 100 mm/min)   :11220, 24420
    Flush NetCDF                             :crit, 24420, 24470

    section CNC motor
    Idle                                     :done, 0, 120
    Forward 22 mm @ 2 mm/s (accel 4 ms)     :active, 120, 11120
    Idle (wait for STOP cmd)                 :done, 11120, 11220
    Return 22 mm @ 100 mm/min               :11220, 24420
    Idle                                     :done, 24420, 24470

    section Pulse controller
    Idle                                     :done, 0, 110
    Armed + generating triggers              :active, 110, 10120
    Stopped                                  :done, 10120, 24470

    section Laser (in FIRE mode — entire mapping)
    Waiting for trigger                      :done, 0, 170
    Firing ×200 shots (mapping area)         :crit, 170, 10070
    Waiting for trigger (between lines)      :done, 10070, 24470

    section Spectrometers (callback mode)
    Armed — waiting for ext. trigger         :done, 30, 170
    Integrating ×200 scans (50 ms each)      :active, 170, 10070
    Stopped (AVS_StopMeasure)                :done, 10070, 24470

    section NetCDF file
    Dark spectrum in memory                  :done, 0, 170
    Progressive writes x=0..199              :active, 170, 10070
    Waiting for flush                        :done, 10070, 24420
    Flush to disk                            :crit, 24420, 24470
```

### Zoom: arm phase (first 300 ms)

```mermaid
gantt
    title Arm phase detail — first 300 ms of a scan line
    dateFormat x
    axisFormat %L ms
    tickInterval 50

    section Software calls
    AVS_PrepareMeasure ×3 devices            :active, 0, 15
    AVS_MeasureCallback(×200) ×3 devices     :active, 15, 30
    sleep(50 ms) before pulse cmd            :done, 30, 80
    Write STEP 80 + read ack                 :active, 80, 90
    sleep(20 ms)                             :done, 90, 110
    Write START                              :crit, 110, 115
    Write $J=G91 X22 F120                    :crit, 115, 120
    First callback fires (x=0)               :active, 170, 230

    section Spectrometers
    Configuring (PrepareMeasure)             :active, 0, 15
    Armed — ext trigger, 200 scans, callback :done, 15, 170
    Shot 1 integration                       :crit, 170, 175
    Shot 2 integration                       :crit, 220, 225
    Shot 3 integration                       :crit, 270, 275

    section Pulse controller
    Receives STEP 80                         :active, 80, 90
    Receives START — armed                   :crit, 110, 115
    Counting CNC steps ...                   :done, 115, 170
    Trigger 1 (80 steps reached)             :crit, 170, 172
    Trigger 2                                :crit, 220, 222
    Trigger 3                                :crit, 270, 272

    section CNC motor
    Idle                                     :done, 0, 120
    Accelerating 0→2 mm/s (4 ms)             :crit, 120, 124
    Constant speed 2 mm/s                    :active, 124, 300

    section Laser
    In FIRE mode — waiting for trigger       :done, 0, 170
    Shot 1 (ext. trigger received)           :crit, 170, 172
    Shot 2                                   :crit, 220, 222
    Shot 3                                   :crit, 270, 272
```

### Key timing notes

- **Laser stays in $FIRE for the entire mapping run**. No commands are sent between lines.
  Only the first line performs `standby_and_fire()`. This minimises CAN bus traffic and
  avoids overrun warnings.
- **All laser telnet commands** are paced with a **1 s minimum gap** (`CMD_GAP_S`) enforced
  in `VironLaser._send()`. `ensure_session()` adds an extra **0.5 s** after `$LOGIN`.
- **Spectrometer collection uses callbacks** (`AVS_MeasureCallback` + `Queue.get`) instead
  of busy-polling with `AVS_PollScan`. The DLL invokes a callback from its own thread;
  the mapping thread blocks efficiently on the queue.
- **`AVS_StopMeasure` is called after every line** (success and failure) to reset DLL/USB
  state. Without this, internal buffers accumulate and spectrometers desynchronize after
  ~190 lines.
- **Pulse controller counter is checked every line** using `RESETCOUNT` (line start) and
  `COUNT` (after forward jog). A CSV log (`pulse_count_log.csv`) records expected vs measured.
- **Pulse parity rule:** line is valid if `COUNT >= expected_shots`; line fails only when
  `COUNT < expected_shots` (extra overscan pulses are accepted).
- **Spectrometers auto-stop** after receiving exactly `x_points` triggers. Extra triggers
  from the margin are silently ignored once the count is reached.
- **`movement_trigger_stop()` is sent immediately after the last stored point** on success,
  preventing additional off-map shots during deceleration/remaining jog distance.
- **On fault**, triggers are stopped immediately — there is no point sending more triggers
  to a faulted laser.
- **Periodic spectrometer re-initialization** runs every `resync_every_n_lines` (default 50)
  to flush long-run DLL/USB state; existing dark is remapped (no new dark capture).
- **Progress PNG generation** sums bands incrementally (one slab at a time) to avoid loading
  the entire multi-GB cube into RAM. Matplotlib figures are wrapped in `try/finally` to
  prevent memory leaks.

## Step-by-step summary

1. **GUI validates** (main thread) that all four devices are connected (CNC, pulse controller, laser, spectrometers) before anything starts.
2. **Pre-established connections** are passed to the background thread — the mapping code never opens its own connections.
3. **MappingThread** (background thread) builds a `MappingParams` dataclass and hands it to `MappingEngine`.
4. **One-time setup** (background thread): logs in to the laser, configures for mapping mode, captures a dark spectrum, creates the NetCDF file, initialises the `CallbackCollector`.
5. **First line**: full `standby_and_fire()` — `$LOGIN`, `$STANDBY`, `wait_ready` (up to 90 s), `$FIRE`, 5 s settle — then scan.
6. **Lines 1..N**: no laser commands at all. The laser stays in `$FIRE` and the hardware trigger chain runs autonomously.
7. **Periodic maintenance**: every `resync_every_n_lines` (default 50), spectrometers are fully re-initialized and callback state is rebuilt; dark is reused (remapped), not recaptured.
8. **_scan_single_line()** — three phases:
   - **Arm**: configure spectrometers for callback-based external-trigger acquisition (`x_points` scans), pulse `RESETCOUNT`, arm pulse controller (`STEP n` + `START`), start CNC X jog (with extra margin beyond mapping area).
   - **Collect**: for each X point, `CallbackCollector.collect_next_shot()` blocks on a `Queue` (DLL callback notification, no polling). Data is dark-corrected, merged across devices, and written to NetCDF.
   - **Cleanup (always)**: `AVS_StopMeasure()` on all spectrometers (resets DLL/USB state).
   - **Cleanup (success)**: `movement_trigger_stop()` immediately after the last stored point, `wait_cnc_idle()`, read pulse `COUNT` (must be `>= x_points`), return CNC to line start, flush NetCDF.
   - **Cleanup (fault)**: `movement_trigger_stop()` immediately, `wait_cnc_idle()`, read pulse `COUNT` for diagnostics, return CNC, raise `ShotTimeoutError`.
9. **Fault detection**: timeout in `collect_next_shot()` **or** pulse parity failure (`COUNT < x_points`) raises `ShotTimeoutError`.
10. **Automatic recovery**: the main loop catches the failure, runs `_recover_laser()`, then full spectrometer re-init + callback rebuild, then retries the same line. After `max_line_retries` consecutive failures on the same line, mapping aborts with a clear error.
11. After each successful line, it moves Y, and every N lines generates a progress image.
12. **Cleanup** (always runs): `$LOGIN` → `$STOP`, close the NetCDF file.

## Configurable fault-recovery parameters (MappingParams)

| Parameter | Default | Description |
|---|---|---|
| `shot_timeout_s` | 30.0 | Seconds to wait for a single spectrometer callback before declaring a timeout |
| `max_line_retries` | 3 | Maximum retry attempts per line before aborting the mapping |
| `line_start_wait_s` | 5.0 | Seconds to wait after `$FIRE` before starting the first scan line |
| `resync_every_n_lines` | 50 | Perform full spectrometer DLL re-init every N lines (`0` disables periodic resync) |

---

## Mapping procedure review (memory, resources, context)

Periodic review of the mapping pipeline for memory leaks, resource lifecycle, and integration with preview, camera, and CNC.

### Memory and resources

| Area | Status | Notes |
|---|---|---|
| **NetCDF** | OK | Single `Dataset` opened in `NetCDFCubeWriter`, closed in `run()`'s `finally` block. No leak. |
| **Progress PNG** | OK | `save_progress_png` uses `with Dataset(..., "r")`; bands summed incrementally (one slab per band) so memory stays flat; `plt.figure()` wrapped in `try/finally` with `plt.close(fig)`. No cube-sized allocation or figure leak. |
| **CallbackCollector** | OK | One collector per run; queues drained at start of each line in `arm()`. `AVS_StopMeasure` after every line prevents DLL buffer buildup. Callback trampoline kept on `self._cb` for GC safety. |
| **Per-line data** | OK | `merged_vecs[x]` is `del`-ed after each `write_xy`; only one X index in memory at a time. |
| **Dark capture** | OK | `capture_dark_once` uses polling then returns; no callback left registered. Next `collector.arm()` re-arms for callback mode. |
| **Laser / CNC / pulse** | OK | Handles are pre-established and passed in; mapping engine does not open or close them. Cleanup only sends `$STOP` and closes NetCDF. |

### GUI and context

| Area | Status | Notes |
|---|---|---|
| **Camera** | OK | `_pause_camera_for_mapping()` stops the camera (and join with timeout); `_finalize_mapping_run()` always calls `_resume_camera_after_mapping()` when the mapping thread ends (success or exception). No leak of camera or thread. |
| **Progress plot** | OK | `ProgressPlotWidget.update_plot()` uses `fig.clear()` then new `imshow(img)`; previous image is dropped. `plt.imread` each refresh is one image in memory. Timer-driven refresh is bounded. |
| **Mapping thread** | OK | `MappingThread` holds references to params and spectrometer data only for the duration of `run()`. After `_finalize_mapping_run()` sets `mapping_thread = None`, the thread object and its references can be GC'd. |
| **Stop / completion** | OK | `_check_mapping_thread()` runs on a timer; when the thread is no longer alive, `_finalize_mapping_run()` runs (disconnect laser, re-enable UI, resume camera and light). Same path for normal completion and error. |

### Bug fixes applied during review

- **Identities vs selected handles**: When `selected_handles` is used, identities are now filtered by building `identity_by_handle` from the original `(handles_sorted, identities)` order, then rebuilding `identities` as `[identity_by_handle[h] for h in handles_sorted]` so device metadata in the NetCDF matches the chosen devices.
- **Default `line_start_wait_s`**: Default in `MappingThread` when building `MappingParams` from the GUI was set to `5.0` (was `10`) to match `MappingParams` and the UI default.

### Recommendations

- **progress_every_lines = 0**: If set to 0, no progress PNG is written; the condition `if p.progress_every_lines and ((y + 1) % ...)` correctly skips. No change needed.
- **Long runs**: For very long maps (many hours), the only long-lived allocations are the NetCDF file (on disk and in the open Dataset) and the CallbackCollector queues (bounded by one notification per shot per device). No unbounded in-memory growth expected.
- **App exit during mapping**: The mapping thread is non-daemon; closing the app may block until the thread exits or the user stops mapping. Consider handling `closeEvent` to set `stop_event` and optionally wait for the thread with a short timeout before quitting.

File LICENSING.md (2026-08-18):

# Licensing

This repository mixes hardware, code, documentation and a few third-party files, so
one license would not fit. Each file has exactly one license, declared in
machine-readable form in `REUSE.toml` following the
[REUSE 3.3 specification](https://reuse.software/spec/). The full text of every
license is in `LICENSES/`, named after its SPDX identifier.

The root `LICENSE` file holds the GPL, because most files in the repository are
code and because GitHub shows only one license per repository. It does not override
the per-file declarations below.

## What is under which license

| Files | SPDX identifier | Why |
| --- | --- | --- |
| `cad/**`, `schematics/*.png` | `CERN-OHL-W-2.0` | CERN Open Hardware License, weakly reciprocal: the usual choice for open hardware, and the one recommended for HardwareX design files |
| `software/acquisition_app/*.py`, `firmware/**/*.ino`, `launch_LIBS.bat`, `config.json`, `requirements.txt` | `GPL-3.0-only` | the license the application was released under |
| `*.md`, `*.html`, `bill_of_materials.csv`, `firmware/Grbl_ESP32_configuration.txt` | `CC-BY-4.0` | documentation and tabular data, reusable with attribution |
| `software/acquisition_app/images/*.svg` | `MIT` | Feather icon set, © 2013–2017 Cole Bemis |
| `avaspec.py`, `avaspec_fix_winfunctype.py` | `LicenseRef-Avantes-SDK` | wrapper for a proprietary library, see below |
| logos, splash screens, `images/icon_aconvert.ico` | `LicenseRef-Logos-Trademarks` | institutional logos are trademarks, see below |

Check a single file with the REUSE tool:

```
pipx run reuse lint
pipx run reuse spdx > sbom.spdx
```

## Two cases that need your attention before you reuse this code

**`avaspec.py` and `avaspec_fix_winfunctype.py`.** These are a ctypes wrapper
around `avaspecx64.dll`, the proprietary Avantes AvaSpec library. The wrapper
follows the structure and the constant names of the Python example distributed with
the Avantes AvaSpec-DLL SDK, so it is best treated as derived from it rather than as
original GPL code. Its use is governed by the terms you accepted with the Avantes
SDK. Neither the DLL nor the Avantes manual is redistributed in this repository:
install the SDK from Avantes and copy `avaspecx64.dll` next to `avaspec.py`. If you
want to reuse the wrapper in another project, clarify the terms with Avantes first.

**Logos and splash screens.** In `software/acquisition_app/`, the files
`LOGO-LEAP-RGB-160x90.png`, `splash.png`, `images/logo.png`, `images/splash.png` and
`images/icon_aconvert.ico` carry the marks
of the Royal Belgian Institute of Natural Sciences, the Geological Survey of Belgium
and the BELSPO LEAP project. Trademarks are not licensed by CC-BY or the GPL. You
may keep them when you run the application as it is, but replace them with your own
if you distribute a modified version, so that your build is not presented as ours.

## Other things not included here

* **Laser control documentation.** The Lumibird/Quantel Viron command set is covered
  by the manufacturer's manual. The Telnet commands actually used are visible in
  `hardware_control.py`.
* **Basler camera runtime.** The optional micro-view camera needs `pypylon` and the
  Basler pylon runtime, installed separately.
* **Hyperspectral cubes.** Full cubes are tens of gigabytes each. One example cube
  is archived on Zenodo under CC-BY-4.0, see `example_data/README.md`; the others
  are available from the corresponding author on request.

## Copyright

Unless a file says otherwise, the copyright is:

```
SPDX-FileCopyrightText: 2021-2026 Royal Belgian Institute of Natural Sciences
                        (Geological Survey of Belgium)
```

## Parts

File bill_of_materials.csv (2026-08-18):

Designator | Component | Number | Cost per unit (€) | Total cost (€) | Source of materials | Material type
Motion | Ball-screw linear modules, SFU1204 + HGH15 rails, incl. NEMA 23 stepper (HANPOSE HPV6; X, Y, Z) | 3 | ≈60–200 (depending on length) | ≈400 | AliExpress | Metal
Motion | Makerbase MKS DLC32 controller board (ESP32, Grbl_ESP32) | 1 | 30 | ≈30 | AliExpress | Semi-conductor
Motion | TMC2209 stepper drivers (3×) + 24 V PSU | 1 set | ≈50 | ≈50 | Mouser | Semi-conductor
Frame | Aluminum extrusion + brackets |  | ≈100 (depends on size) | ≈100 | 123-3D.nl | Metal
Trigger | Arduino Uno (pulse controller) | 1 | ≈25 | ≈25 | Mouser | Semi-conductor
Laser assembly | Arduino Nano (internal controller) | 1 | ≈25 | ≈25 | Mouser | Semi-conductor
Laser assembly | Illumination LEDs (micro + macro) + drivers | 1 | ≈20 | ≈20 | Mouser | Semi-conductor
Laser assembly | Machine-vision camera, Basler pulse USB3 (CS-mount), e.g. puA1920-30uc | 1 | ≈400 | ≈400 | Edmund Optics | Semi-conductor
Laser assembly | 45° longpass dichroic mirror, 950 nm cut-on (Thorlabs DMLP950), in a 45° kinematic cage mount (Thorlabs KC45D1, ≈€230) | 1 | ≈600 | ≈600 | Thorlabs | Inorganic
Laser assembly | Focusing lens, UVFS plano-convex, Ø25.4 mm, f = 50 mm | 1 | ≈60 | ≈60 | Thorlabs | Ceramic
Laser assembly | 30 mm cage plates, rods + mounting bases (Thorlabs CP02 ×3, CP30, ER6 rods ×4, CPB1/M, LCPB1) | 1 set | ≈200 | ≈200 | Thorlabs | Metal
Laser assembly | Collection optics: trifurcated 600 µm 0.22 NA low-OH fiber + 2 collimators (Ø12.7 mm UVFS plano-convex, f = 50 mm and f = 25 mm) | 2 | ≈300 | ≈600 | Ocean Optics | Composite
Laser assembly | 3D-printed focusing head and enclosure parts | ≈1kg | ≈25 (filament) | ≈25 | printed in-house | Polymer
Laser assembly | Air pump for the focusing-head overpressure, 0–30 L/min, ≤30 kPa, <40 dB (SCULPFUN Air Assist, 230 V AC) | 1 | ≈60 | ≈60 | Amazon | Composite
Sample holder | Photographic leveling base, ±15° tilt, 20 kg load (ARTCISE LH6) | 1 | ≈50 | ≈50 | Amazon | Metal
Safety | Emergency-stop button, 22 mm, NC, 660 V/10 A | 1 | ≈20 | ≈20 | Amazon | Other
Extraction | Mobile fume extractor, 235 m³/h, H13 HEPA + 3 kg activated carbon, 130 cm extraction arm (PureAirPro 6001D) | 1 | ≈800 | ≈800 | Itec Luchtreiniging | Composite
Laser | Lumibird/Quantel Viron Nd:YAG 1064 nm | 1 | ≈25,000–30,000 (quote) | On quotation | Lumibird | Other
Spectrometers | Avantes spectrometers (4× AvaSpec-ULS4096CL-EVO, 1× ULS2048CL-EVO, 1× VRS2048CLIR-EVO; 200–1100 nm) | 6 | quote (typically ≈5-6,000 per channel, configuration-dependent) | On quotation | Avantes | Other
Acquisition | Industrial 7-port USB 3.0 hub (StarTech), powered | 1 | ≈300 | ≈300 | StarTech.com | Semi-conductor
Safety | Enclosure frame (aluminum profiles and wood panels), door interlock switch wired to the laser interlock input, warning signage | 1 | ≈300 | ≈300 | Local supplier | Composite
Total | Sum of the 19 priced lines above, rounded to ≈€4 100 in the article; the laser and the spectrometers are quoted separately and are not included |  |  | ≈4 065

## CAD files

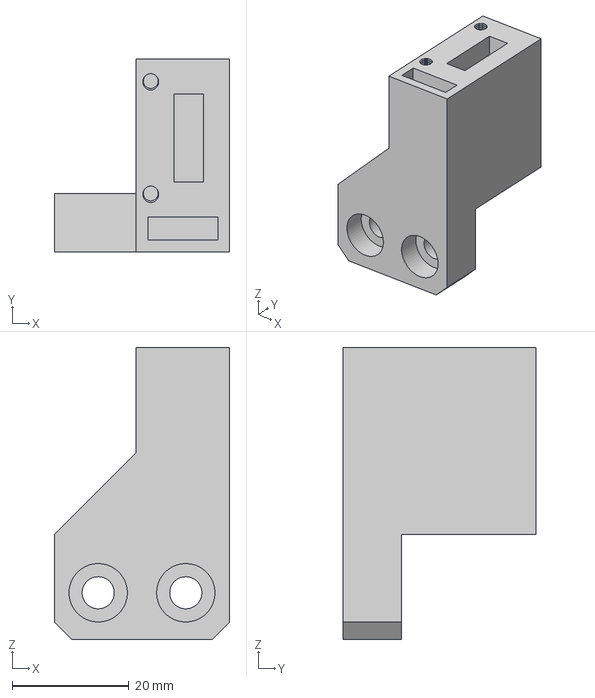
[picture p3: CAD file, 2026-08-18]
cad/End_Stop_Board_libs.step
30.0 x 33.0 x 50.0 mm

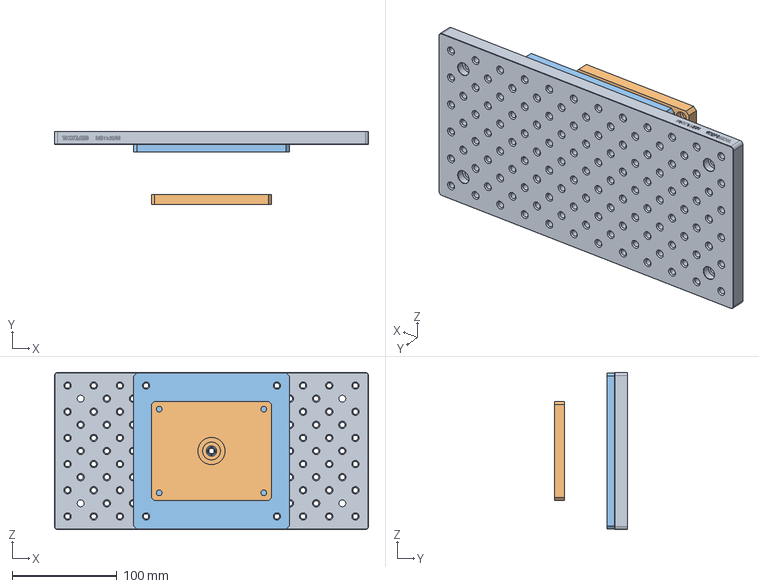
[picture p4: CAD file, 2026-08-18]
cad/Screen_libs_sample_stage_plates.step
300.0 x 70.2 x 150.0 mm
MB1530_M - Aluminium Breadboard 150 x 300 x 12.7mm_MB3030_M-1
ADAPTER_ball_plate

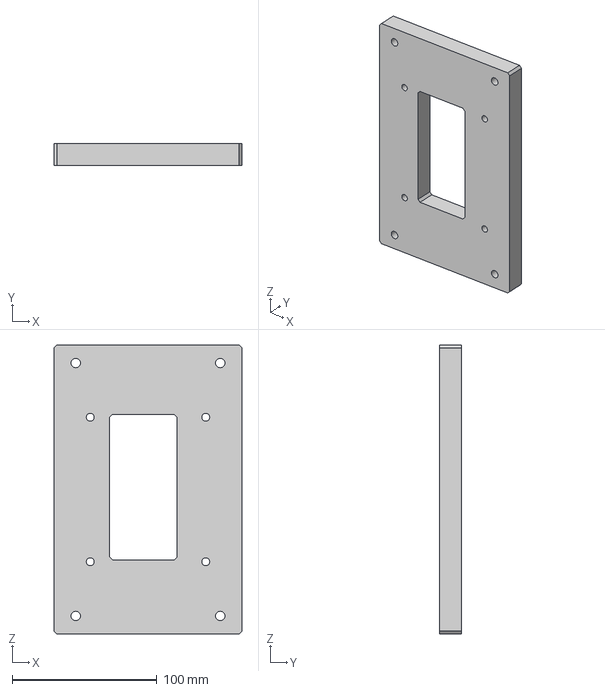
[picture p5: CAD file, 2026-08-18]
cad/Screen_libs_Z_mounting_plate.step
130.0 x 15.0 x 200.0 mm

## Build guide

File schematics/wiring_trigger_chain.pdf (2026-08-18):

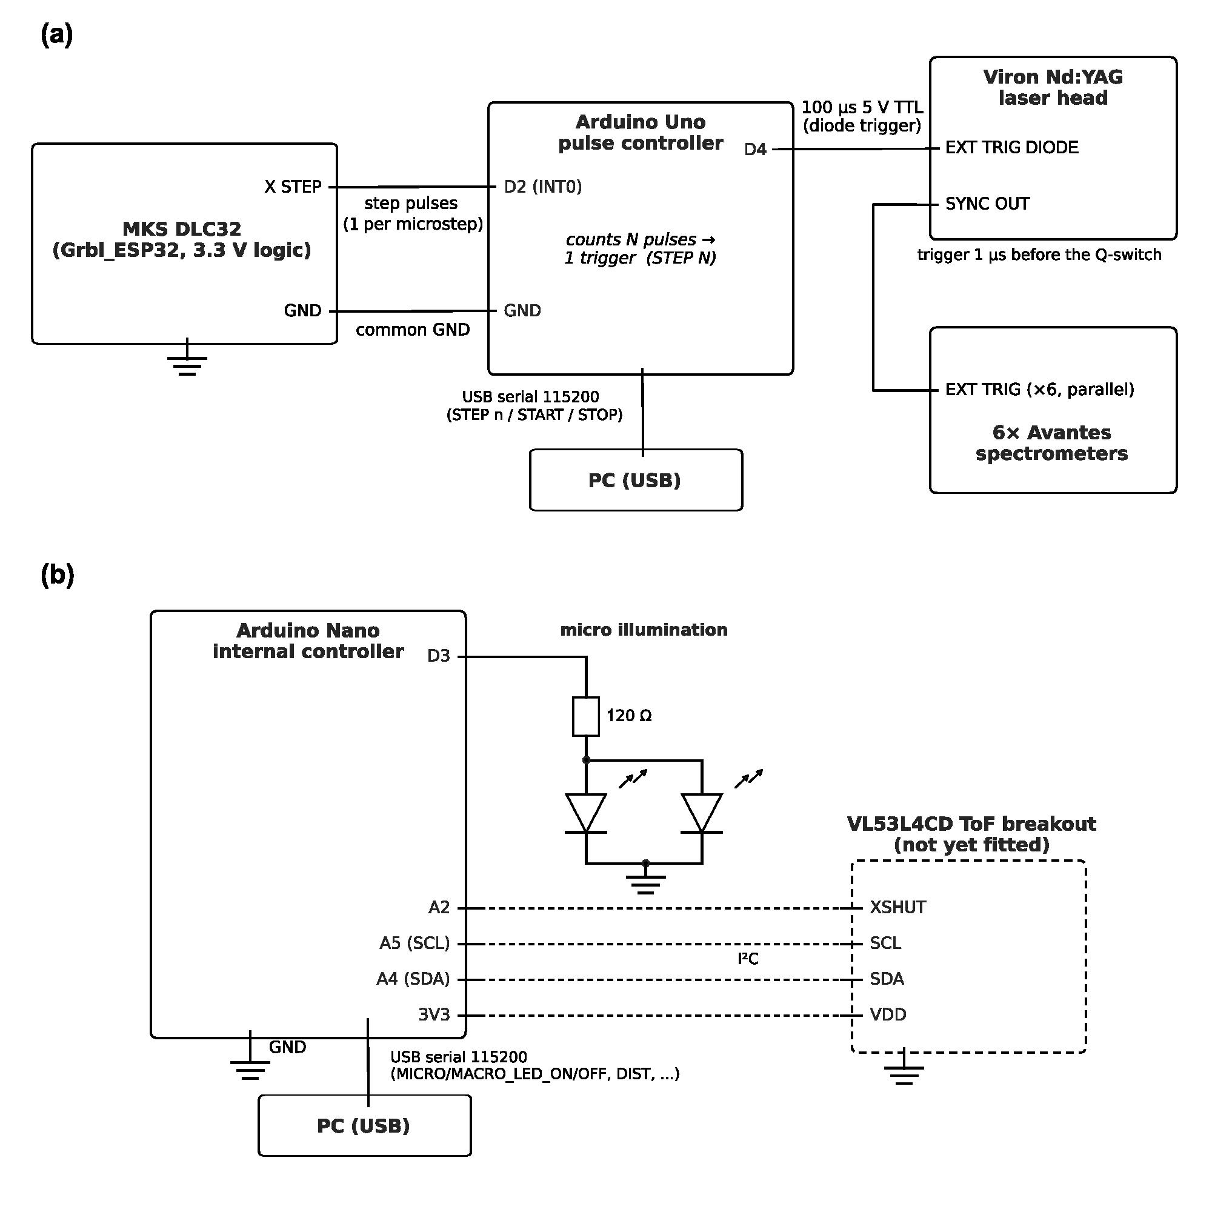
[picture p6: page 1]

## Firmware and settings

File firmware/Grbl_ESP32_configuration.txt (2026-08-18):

# Grbl_ESP32 settings — LIBS elemental imager
# Makerbase MKS DLC32 (ESP32) with three TMC2209 drivers at 1/16 microstepping,
# SFU1204 ball-screw modules (4 mm lead), 200 step/turn motors.
#
# Send these lines to the controller over the serial console (115200 baud), then
# read them back with "$$" and store the answer next to this file. Values marked
# <TODO> depend on your own mechanics and must be measured on the machine; the
# comments say how.
#
# Axis convention used throughout the article: X is the fast scan axis, Y steps
# between lines, Z sets the working distance.

# --- resolution -------------------------------------------------------------
# 200 steps/turn x 16 microsteps / 4 mm lead = 800 steps/mm (1.25 um per microstep).
# Change only if the screw lead or the microstepping differs.
$100=800    ; X steps/mm
$101=800    ; Y steps/mm
$102=800    ; Z steps/mm

# --- speeds -----------------------------------------------------------------
# The drivers are undersized with respect to the motors, so the feed is kept low
# to avoid skipped steps (article Section 7.7). 250 mm/min is the practical
# ceiling of this build; the mapping feed is computed by the acquisition software
# from the pitch and the laser repetition rate and is always below it.
$110=250    ; X max rate (mm/min)
$111=250    ; Y max rate (mm/min)
$112=250    ; Z max rate (mm/min)

# --- accelerations ----------------------------------------------------------
# Must be low enough that no step is skipped at the start and at the end of a
# line, and that the laser repetition rate stays inside its allowed window
# (10-20 Hz for the Viron) while the axis ramps up. Start low, increase until
# the position after a long back-and-forth test no longer drifts, then keep
# about half of that value.
$120=<TODO> ; X acceleration (mm/s^2)
$121=<TODO> ; Y acceleration (mm/s^2)
$122=<TODO> ; Z acceleration (mm/s^2)

# --- travel and limits ------------------------------------------------------
# Travel of the modules used here; adapt to your own axes.
$130=800    ; X max travel (mm)
$131=400    ; Y max travel (mm)
$132=200    ; Z max travel (mm)
$20=1       ; soft limits enabled
$21=1       ; hard limits enabled (end-stop board, see cad/End_Stop_Board_libs.step)
$22=1       ; homing cycle enabled

# --- wiring-dependent flags -------------------------------------------------
# These depend on how the motors and switches are plugged in. Read them from
# your working machine with "$$" instead of guessing.
$3=<TODO>   ; direction invert mask
$4=<TODO>   ; step enable invert
$5=<TODO>   ; limit pin invert
$23=<TODO>  ; homing direction invert mask
$24=<TODO>  ; homing feed (mm/min)
$25=<TODO>  ; homing seek (mm/min)
$27=<TODO>  ; homing pull-off (mm)

# --- notes ------------------------------------------------------------------
# * The step signal of the X axis is tapped on the board and fed to D2 (INT0) of
#   the Arduino Uno pulse controller, which divides it and triggers the laser.
#   Any change of $100 therefore changes the shot pitch for a given divider
#   value, so the acquisition software must be told the same steps/mm value.
# * Do not enable any "step smoothing" or lookahead option that changes the
#   number of emitted step pulses: the pixel grid is counted from those pulses.
# * TMC2209 current is set in the driver configuration of the firmware build;
#   keep it at the value that the motors tolerate thermally over a full day of
#   mapping.

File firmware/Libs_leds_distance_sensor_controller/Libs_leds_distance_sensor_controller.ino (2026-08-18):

////////////////////////////////////////////////////////////////////////////////
// LIBS Internal Controller                                                   //
// Geological Survey of Belgium - 02/2026                                     //
//                                                                            //
// Serial command interface for controlling LEDs and a VL53L4CD ToF distance  //
// sensor used in a LIBS (Laser-Induced Breakdown Spectroscopy) setup.        //
//                                                                            //
// Features:                                                                  //
//   - Micro and macro LED control (on/off)                                   //
//   - VL53L4CD time-of-flight distance sensor with on-demand measurements    //
//   - Sensor power management via XSHUT (hardware standby)                   //
//                                                                            //
// Serial protocol: 115200 baud, newline-terminated string commands.          //
// Send "H" for a list of available commands.                                 //
//                                                                            //
// Pin assignments:                                                           //
//   LED_BUILTIN  - status LED                                                //
//   D3           - micro LED                                                 //
//   A3           - macro LED                                                 //
//   A2           - VL53L4CD XSHUT                                            //
//   SDA/SCL      - VL53L4CD I2C                                              //
////////////////////////////////////////////////////////////////////////////////

#include <Arduino.h>
#include <Wire.h>
#include <vl53l4cd_class.h>
#include <string.h>
#include <stdlib.h>
#include <stdio.h>
#include <stdint.h>

#define DEV_I2C Wire

// pin declarations
const int ledpin =  LED_BUILTIN;
const int led_micro =  3;
const int led_macro =  A3;
const int xshut_pin = A2;  // XSHUT pin for VL53L4CD

String device_name = "Libs internal controller";
String device_version = "v2";

// VL53L4CD distance sensor
VL53L4CD sensor_vl53l4cd_sat(&DEV_I2C, xshut_pin);
bool sensor_powered = false;

// Initialize (or reinitialize) the VL53L4CD sensor
void initSensor() {
  DEV_I2C.begin();
  sensor_vl53l4cd_sat.begin();
  sensor_vl53l4cd_sat.VL53L4CD_Off();
  sensor_vl53l4cd_sat.InitSensor();
  sensor_vl53l4cd_sat.VL53L4CD_SetRangeTiming(200, 0);
}

//----------------------------------SETUP------------------------------------

void setup() {

  pinMode(ledpin, OUTPUT);
  pinMode(led_micro, OUTPUT);
  pinMode(led_macro, OUTPUT);
  digitalWrite(ledpin, 0);
  digitalWrite(led_micro, 0);
  digitalWrite(led_macro, 0);

  Serial.begin(115200);

  // Initialize I2C bus
  DEV_I2C.begin();

  // Put sensor in standby at startup (XSHUT low)
  sensor_vl53l4cd_sat.VL53L4CD_Off();
}


void loop() {

  // check if data has been sent from the computer:
  if (Serial.available()) {
    String command = Serial.readStringUntil('\n');
    command.trim();  // remove any trailing \r or spaces

        if (command == "?") {
        Serial.print(device_name);
        Serial.print(",");
        Serial.print(device_version);
        Serial.print("\r\n");
        delay(100);
        }

        else if (command == "H") {
        Serial.print("?                returns ID,version");
        Serial.print("\r\n");
        Serial.print("MICRO_LED_ON     turn LED micro ON");
        Serial.print("\r\n");
        Serial.print("MICRO_LED_OFF    turn LED micro OFF");
        Serial.print("\r\n");
        Serial.print("MACRO_LED_ON     turn LED macro ON");
        Serial.print("\r\n");
        Serial.print("MACRO_LED_OFF    turn LED macro OFF");
        Serial.print("\r\n");
        Serial.print("SENSOR_ON        wake up + init distance sensor");
        Serial.print("\r\n");
        Serial.print("SENSOR_OFF       put distance sensor in standby");
        Serial.print("\r\n");
        Serial.print("DIST             distance measurement (mm)");
        Serial.print("\r\n");
        Serial.print("DIST_DIAG        distance measurement (verbose)");
        Serial.print("\r\n");
        delay(100);
        }

        else if (command == "ON") {
        digitalWrite(led_micro, 1);
        Serial.print("led micro ON");
        Serial.print("\r\n");
        }

        else if (command == "OFF") {
        digitalWrite(led_micro, 0);
        Serial.print("led micro OFF");
        Serial.print("\r\n");
        }

        else if (command == "MACRO_LED_ON") {
        digitalWrite(led_macro, 1);
        Serial.print("led macro ON");
        Serial.print("\r\n");
        }

        else if (command == "MACRO_LED_OFF") {
        digitalWrite(led_macro, 0);
        Serial.print("led macro OFF");
        Serial.print("\r\n");
        }

        else if (command == "SENSOR_ON") {
        initSensor();
        sensor_powered = true;
        Serial.print("distance sensor ON");
        Serial.print("\r\n");
        }

        else if (command == "SENSOR_OFF") {
        sensor_vl53l4cd_sat.VL53L4CD_Off();  // XSHUT low = hardware standby
        sensor_powered = false;
        Serial.print("distance sensor OFF");
        Serial.print("\r\n");
        }

        else if (command == "DIST" || command == "DIST_DIAG") {
        if (!sensor_powered) {
          Serial.println("ERROR: sensor is OFF, send SENSOR_ON first");
        } else {
          // Trigger a distance measurement using VL53L4CD
          uint8_t NewDataReady = 0;
          VL53L4CD_Result_t results;
          uint8_t status;

          // Start ranging
          sensor_vl53l4cd_sat.VL53L4CD_StartRanging();

          // Wait for new data to be ready
          do {
            status = sensor_vl53l4cd_sat.VL53L4CD_CheckForDataReady(&NewDataReady);
          } while (!NewDataReady);

          if ((!status) && (NewDataReady != 0)) {
            // Clear HW interrupt to restart measurements
            sensor_vl53l4cd_sat.VL53L4CD_ClearInterrupt();

            // Read measured distance. RangeStatus = 0 means valid data
            sensor_vl53l4cd_sat.VL53L4CD_GetResult(&results);

            if (command == "DIST_DIAG") {
              char report[64];
              snprintf(report, sizeof(report), "Status = %3u, Distance = %5u mm, Signal = %6u kcps/spad",
                       results.range_status,
                       results.distance_mm,
                       results.signal_per_spad_kcps);
              Serial.println(report);
            } else {
              Serial.println(results.distance_mm);
            }
          } else {
            Serial.println("ERROR: measurement failed");
          }

          // Stop ranging
          sensor_vl53l4cd_sat.VL53L4CD_StopRanging();
        }
        }

  }
}

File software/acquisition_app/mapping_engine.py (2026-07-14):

# -*- coding: utf-8 -*-
"""
LIBS Mapping Engine
-------------------
Class-based mapping engine for streamed NetCDF acquisition with GRBL CNC,
pulse controller, Viron laser, and Avantes spectrometers.

Used by ``mapping_gui.MappingThread`` inside the main application.
"""
import os
import time
import queue as _queue
from datetime import datetime
from dataclasses import dataclass
from typing import Optional, Callable

import numpy as np
from netCDF4 import Dataset
import ftplib

# Headless-safe plotting
import matplotlib
matplotlib.use("Agg")
import matplotlib.pyplot as plt

import avaspec_fix_winfunctype as avs
from hardware_control import (
    wait_cnc_idle, grbl_stream_jog_x, grbl_stream_jog_y,
    movement_trigger_start, movement_trigger_stop,
    movement_trigger_reset_count, movement_trigger_get_count,
)


class ShotTimeoutError(Exception):
    """Raised when waiting for spectrometer data times out (likely laser fault)."""
    pass


# ============================
# Element band dictionary
# ============================
BAND_DICT = {
    "Si": [251.61, 288.16],
    "Al": [308.22, 394.40, 396.15],
    "Fe": [248.33, 371.99, 374.55, 382.04, 438.35, 516.89],
    "Mg": [279.55, 285.21, 517.27],
    "Ca": [393.37, 396.85, 422.67],
    "Na": [588.995, 589.592],
    "K":  [766.49, 769.90],
    "Ti": [334.94, 337.28],
    "Mn": [403.08, 293.31],
    "O":  [777.19, 844.62],
    "Ba": [455.40, 493.41, 553.55, 614.17],
    "Sr": [407.77, 421.55, 460.73],
    "Cu": [324.75, 327.40],
    "Zn": [213.86, 468.01, 472.22],
    "P":  [213.62, 214.91],
    "S":  [906.89, 910.48, 912.74, 937.42],   # S II lines above 900 nm
    "Li": [610.36, 670.78],
    "Pb": [280.20, 283.31, 363.96, 368.35, 405.78],
}


# ============================
# MappingParams dataclass
# ============================
@dataclass
class MappingParams:
    """All parameters needed for a mapping run, replacing 30+ module-level variables."""
    # Mapping dimensions
    step_size: float = 0.10
    mapping_X_size: float = 20.0
    mapping_Y_size: float = 3.0

    # Laser & timing
    laser_frequency: float = 20.0
    integration_time_ms: float = 0.1
    integration_delay_ns: int = 1000
    averages: int = 1

    # CNC / pulse
    steps_per_mm: int = 800
    return_feed_mm_min: float = 100.0

    # Laser
    laser_single_shot_mode: bool = False
    line_start_wait_s: float = 5.0  # seconds to wait at start of each line after fire

    # Output
    save_dir: str = "output_job"
    save_stem: str = "mapping_run"
    progress_every_lines: int = 5
    progress_selection: str = "Sr"
    progress_tol_nm: float = 0.3

    # FTP (optional)
    ftp_host: Optional[str] = None
    ftp_user: Optional[str] = None
    ftp_pass: Optional[str] = None
    ftp_path: str = "."

    # Fault recovery
    max_line_retries: int = 3
    shot_timeout_s: float = 30.0
    resync_every_n_lines: int = 50

    # Verbosity
    verbose: bool = True

    # --- Derived (computed after construction) ---
    @property
    def mapping_X_points(self) -> int:
        return int(self.mapping_X_size / self.step_size)

    @property
    def mapping_Y_points(self) -> int:
        return int(self.mapping_Y_size / self.step_size)

    @property
    def x_travel_mm(self) -> float:
        return self.mapping_X_size + (self.step_size * 10.0)

    @property
    def x_speed_mm_s(self) -> float:
        return self.step_size * self.laser_frequency

    @property
    def x_feed_mm_min(self) -> float:
        return self.x_speed_mm_s * 60.0

    @property
    def step_trigger(self) -> int:
        return int(round(self.steps_per_mm * self.step_size))

    @property
    def mapping_filename_nc(self) -> str:
        # Cache so the timestamp is consistent across multiple accesses
        if not hasattr(self, '_cached_filename_nc'):
            stamp = datetime.now().strftime("%Y%m%d_%H%M%S")
            object.__setattr__(self, '_cached_filename_nc', f"{self.save_stem}_{stamp}.nc")
        return self._cached_filename_nc


# ============================
# Utility functions
# ============================
def ns_to_fpga_ticks(ns):
    """Convert nanoseconds to 48 MHz FPGA tick units (~20.83 ns/tick)."""
    return int(round(ns / 20.83)) if ns else 0
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

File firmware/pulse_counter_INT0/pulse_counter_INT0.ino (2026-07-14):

#include <SerialCommand.h>   /* http://github.com/p-v-o-s/Arduino-SerialCommand */

//Number of pulses, used to measure energy.
volatile long pulseCount = 0;
volatile unsigned long trigger_emit_count = 0;
int first_pulse = 0;

//Used to measure power.
unsigned long pulseTime,lastTime;

//power and energy
double timer;
const int trigger_pin = 4 ;
volatile int step_target=1;

// Non-blocking trigger: ISR only sets pin HIGH; loop() turns it LOW after 100 us.
// Avoids missing step pulses when we used delayMicroseconds() inside the ISR.
volatile unsigned long trigger_off_at_micros = 0;  // 0 = no pending turn-off
const unsigned int trigger_pulse_us = 100;

SerialCommand sCmd(Serial);// the SerialCommand parser object

void setup()
{
    Serial.begin(115200);
    while (!Serial) {    ; // wait for serial port to connect. Needed for native USB port only
    }
    pinMode(trigger_pin, OUTPUT) ;
    pinMode(LED_BUILTIN, OUTPUT);
    pinMode(2, INPUT);
    digitalWrite(trigger_pin, 0);
    // KWH interrupt attached to IRQ 0 = pin2

sCmd.setDefaultHandler(UNRECOGNIZED_sCmd_default_handler);
sCmd.addCommand("STEP", STEP_sCmd_config_handler);     //configures integration time
sCmd.addCommand("START", START_sCmd_query_handler);       //reads out the whole spectrum
sCmd.addCommand("STOP", STOP_sCmd_query_handler);   //reads out timings
sCmd.addCommand("COUNT", COUNT_sCmd_query_handler);   //reads out emitted trigger count
sCmd.addCommand("RESETCOUNT", RESETCOUNT_sCmd_query_handler);   //resets emitted trigger count
sCmd.addCommand("FILTER", STOP_sCmd_query_handler);   //reads out timings
sCmd.addCommand("PUMP_ON", STOP_sCmd_query_handler);   //reads out timings
sCmd.addCommand("PUMP_OFF", STOP_sCmd_query_handler);   //reads out timings
sCmd.addCommand("H", HELP_sCmd_query_handler);   //reads out timings
sCmd.addCommand("?", IDENTITY_sCmd_query_handler);   //reads out timings

}

void loop()
{
  // Turn trigger pin LOW after 100 us (non-blocking; keeps ISR short so we don't miss steps).
  // Read trigger_off_at_micros with interrupts off (4-byte read is not atomic on AVR).
  noInterrupts();
  unsigned long t_off = trigger_off_at_micros;
  interrupts();
  if (t_off != 0 && (long)(micros() - t_off) >= 0) {
    digitalWrite(trigger_pin, 0);
    trigger_off_at_micros = 0;
  }

  int num_bytes = sCmd.readSerial();      // fill the buffer
  if (num_bytes > 0){
    sCmd.processCommand();  // process the command
  }
}

// Unrecognized command
void UNRECOGNIZED_sCmd_default_handler(SerialCommand this_sCmd)
{
  SerialCommand::CommandInfo command = this_sCmd.getCurrentCommand();
  this_sCmd.print(F("### Error: command '"));
  this_sCmd.print(command.name);
  this_sCmd.print(F("' not recognized ###\n"));
}

void STEP_sCmd_config_handler(SerialCommand this_sCmd){
  char *arg = this_sCmd.next();
  if (arg == NULL){
    this_sCmd.println(F("### Error: STEP command requires 1 argument 'STEP NUMBER'"));
  }
  else{
    step_target = atoi(arg);
    this_sCmd.print(F("STEP : "));
    this_sCmd.println(step_target);
  }
}

void START_sCmd_query_handler(SerialCommand this_sCmd){
  attachInterrupt(digitalPinToInterrupt(2), onPulse, RISING);
  pulseCount = 0;
  first_pulse = 0;
  this_sCmd.println(F("START : START pulsing with external interrupt"));
  
}
void STOP_sCmd_query_handler(SerialCommand this_sCmd){
  detachInterrupt(digitalPinToInterrupt(2));
  this_sCmd.println(F("STOP pulsing with external interrupt"));
}

void COUNT_sCmd_query_handler(SerialCommand this_sCmd){
  noInterrupts();
  unsigned long count = trigger_emit_count;
  interrupts();
  this_sCmd.print(F("COUNT : "));
  this_sCmd.println(count);
}

void RESETCOUNT_sCmd_query_handler(SerialCommand this_sCmd){
  noInterrupts();
  trigger_emit_count = 0;
  pulseCount = 0;
  interrupts();
  this_sCmd.println(F("RESETCOUNT : 0"));
}

void HELP_sCmd_query_handler(SerialCommand this_sCmd){
  this_sCmd.println(F("STEP : define number of motor steps or microsteps befor laser pulse"));
  this_sCmd.println(F("START : START pulsing with external interrupt"));
  this_sCmd.println(F("STOP : STOP pulsing with external interrupt"));
  this_sCmd.println(F("COUNT : read emitted trigger count"));
  this_sCmd.println(F("RESETCOUNT : reset emitted trigger count"));
  this_sCmd.println(F("FILTER : TOGGLE filter machine"));
  this_sCmd.println(F("PUMP_ON : Start the pump"));
  this_sCmd.println(F("PUMP_OFF : Stop the pump"));  
  this_sCmd.println(F("H : list commands"));
  this_sCmd.println(F("? : identify device"));
}

void IDENTITY_sCmd_query_handler(SerialCommand this_sCmd){
  this_sCmd.println(F("LIBS motor pulse counter v1.1"));
}


// The interrupt routine — keep it minimal: no delayMicroseconds() here or we miss step pulses.
void onPulse()
{
  pulseCount++;

  if (pulseCount == step_target) {
    digitalWrite(trigger_pin, 1);
    trigger_off_at_micros = micros() + trigger_pulse_us;  // loop() will turn off after 100 us
    trigger_emit_count++;
    pulseCount = 0;
  }
}

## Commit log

2026-08-18 Add the HardwareX design package and per-file licensing
    Folds the archived design package of the HardwareX article into this repository:
    STEP models in cad/, the two Arduino sketches and the Grbl_ESP32 settings in
    firmware/, a snapshot of the Hypercube Explorer, documentation in docs/, the bill
    of materials, and a README that ties the parts to the article.
    Licensing is declared per file in REUSE.toml (REUSE 3.3): CERN-OHL-W-2.0 for the
    CAD, GPL-3.0-only for firmware and application code, CC-BY-4.0 for documentation
    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
    [End_Stop_Board_libs.step, Grbl_ESP32_configuration.txt, Screen_libs_Z_mounting_plate.step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]
2026-08-18 Give the repository the same shape as the archive
    The acquisition application was sitting loose at the repository root, mixed with the
    new folders, which made the layout hard to read. It moves to
    software/acquisition_app/, so the root holds only the licensing, the README and the
    top-level folders, exactly like the Zenodo archive.
    Also adds schematics/, with Fig. 7 of the article: the design-files table promises a
    wiring schematic in the repository. The two documentation pages that duplicated the
    archive are folded into software/README.md, and the development notes travel with the
    application. Paths in README.md, LICENSING.md and REUSE.toml follow, and the Zenodo
    DOI of the archive is filled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
    [Bruniquel_LIBS_improved.py, app_init.py, avaspec.py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]
2026-08-18 Use the file names the submitted article promises
    The design-files table of the article names the electronics enclosure
    Screen_libs_pulse_controller_box.step and lists the wiring schematic as a PDF. The
    article is submitted, so the repository follows it: the CAD archive and the STEP file
    inside it are renamed, and a printable PDF of Fig. 7 sits next to the PNG.
